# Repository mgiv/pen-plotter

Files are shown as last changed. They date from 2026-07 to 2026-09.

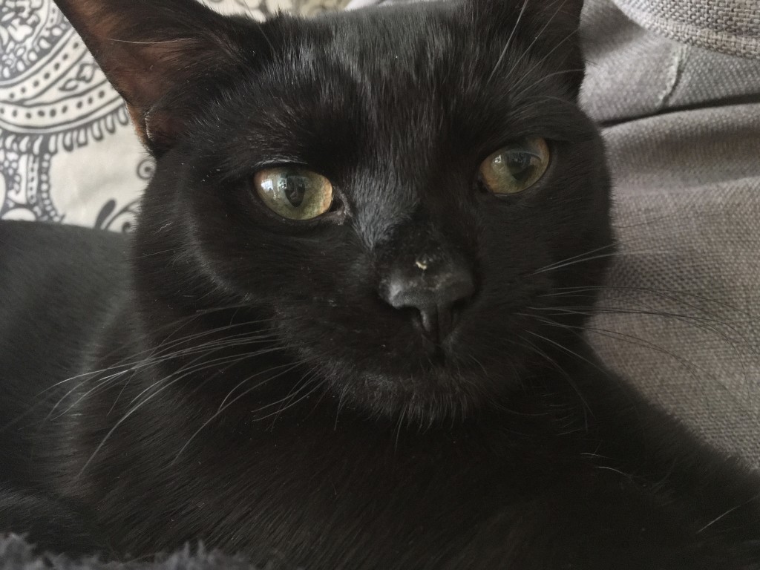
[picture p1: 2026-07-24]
code/TPGen/test-images/1.jpg

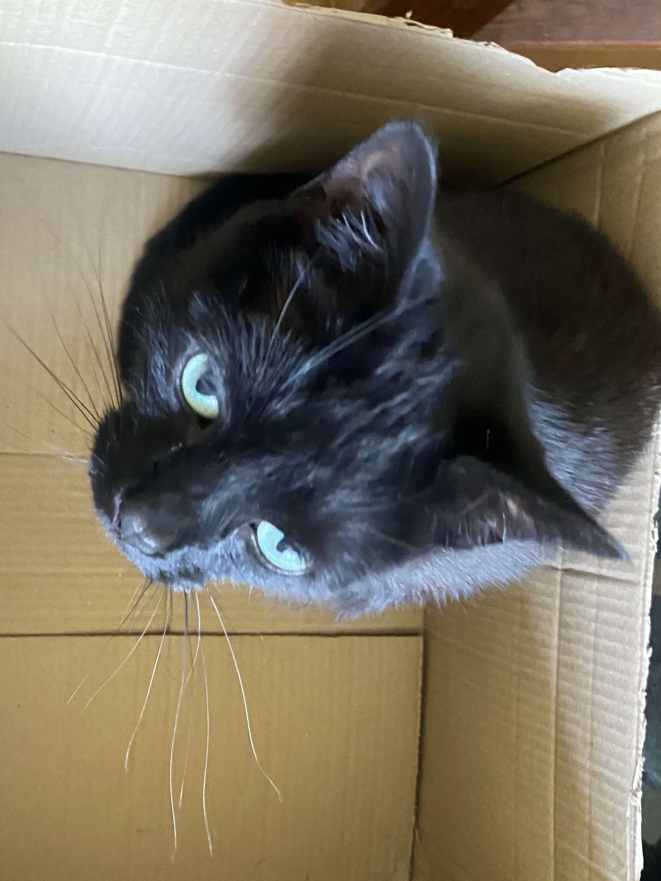
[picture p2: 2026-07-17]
code/TPGen/test-images/7.jpg

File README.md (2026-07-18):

# Pen plotter
## A simple pen plotter using an esp32, stepper motors, a servo and timing belts
### Demo videos
- [Demo 1 - Hilbert curves](https://www.youtube.com/watch?v=iywQXDerfF4)  
- [Demo 2 - Cat](https://www.youtube.com/shorts/F5tRbeLazfQ)  
- [Demo 3 - Triangles](https://www.youtube.com/shorts/Yr_N4DkdwpU)  
- [Demo 4 - Another Cat](https://www.youtube.com/shorts/lvt_kN0ZHD0)  

### Capabilities
#### It can convert images into lines, where the amount of lines shows the darkness of the pixels. Also, it can use canny edge detection to convert images into paths, and from there into drawings
cat  
{EF9DE653-6C88-40CC-B70B-28055ED8D5D0}

#### It can also draw hilbert curves and sierpinski triangles
{B3DB4044-183A-462D-B0FC-778355AC7D37}  
{AF7F2D5E-4E53-49CD-B731-9960951EA636}

#### Other features
- Auto Homing: Can return to (0, 0) automatically
- E-Stop Button: Stop suddenly when things go wrong
- Adjustable Pen Holder: Support for pens of all shapes and sizes
- Easy Assembly (Well... It's not that easy, but easier than the last version)
- Precise movement

### Design
The plotter uses a cartesian gantry system. Originally I was going to use a bed slinger system, like the Bambu Lab A1 Mini, however I decided to redesign it to corexy. After I realised how hard corexy would be to implement, I modified it to use the gantry.  
{F74FA99E-C383-4A17-BCB6-C585A155FD70}

There's 3 stepper motors, driven by 2 A4988 drivers. 2 of the motors are wired in series on the drivers, which makes sense since they're both on the y axis.

**Electronics**
- I used an ESP32, which is useful because it runs python, runs wifi, and is also far more capable than an arduino. I'm not using the wifi at the moment but might do later.
- The stepper drivers are A4988. I used generic breakout boards and soldered together a custom board with them that integrates the 2 of them with merged power, enable and gnd pins.
- The steppers are generic nema 17 motors, using 1/16 step
- The servo is a cheap SG90

### Print settings
- .28mm layer height, ~20-30% gyroid infill
- Auto supports
- Almost anything would work to be honest as long as it prints

### BOM
- 8mmx300mm steel linear rod (4x)
- M3 Nuts/Bolts
- NEMA 17 Stepper motors (3x)
- GT2 Timing belts (~3m)
- GT2 Spring belt tensioners (4-8x)
- GT2 Idlers (3x)
- GT2 Drive Pulleys (3x)
- Any random button/microswitch (3x)
- _Some_ M5 bolts (although 3d printed replacements would do)
- Wood screws/hot glue (anything to attach to baseboard)

### Build advice
If you want to print this yourself, I wouldn't recommend it. While it is in a working state, there are a lot of issues with the build that either make it a pain to build or just not work at all. If you do insist on building it yourself, find some random piece of wood or plastic to use as the baseboard. In a future version I'll improve the mounting holes and also make a semi-ridgid frame to help align it.

#### Instructions
1. Attach motors to parts using M3 screws.
2. Put the pen lift arm on the carriage
3. Assemble all the parts as shown without the timing belts. Take care not to bend the steel rods
4. Add the timing belts. Try to make them as tight as possible
5. If needed, add belt tensioning springs.
6. Wire the 2 Y axis motors in series
7. Either create or buy some dual stepper driver board (note that the 3 are treated as 2 motors because 2 of them are in series)
8. Press fit the servo into place, and (depending on print precision) add screws to hold in place if needed

### Credits
- Sierpinski triangle algorithm modified from https://runestone.academy/ns/books/published/pythonds/Recursion/pythondsSierpinskiTriangle.html
- Hilbert curve algorithm modified from https://www.compuphase.com/hilbert.htm
- Parts of edge detection algorithm modified from https://learnopencv.com/edge-detection-using-opencv/

### AI Usage
AI was used in doing research on components and design ideas, as well as for troubleshooting, and for advice about algorithms to use. It was also used for doing research on micropython and debugging code

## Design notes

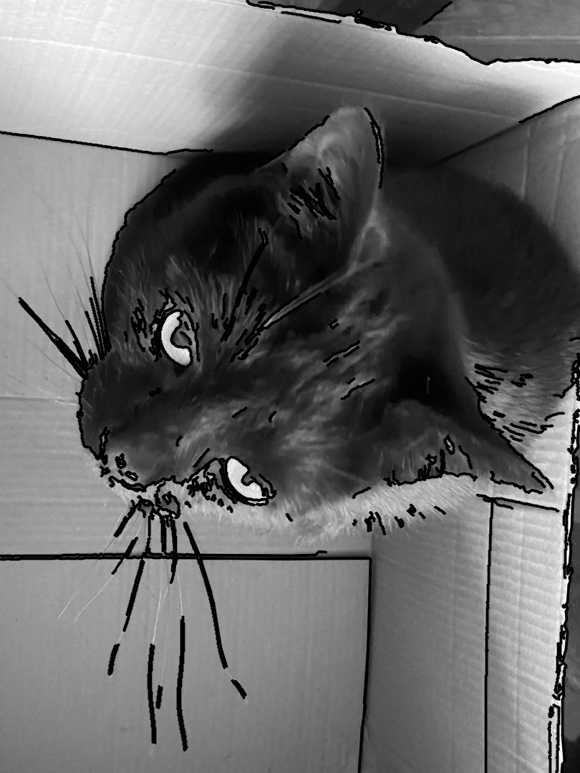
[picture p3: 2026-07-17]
code/TPGen/contours_none_image1.jpg

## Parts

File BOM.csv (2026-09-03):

Item Number | Part Name | Additional information | Quantity | Source | Unit cost (£) | Total cost (£)
1 | Stainess steel linear rods | 8mmx300mm | 4 | Purchased | £2.50 | £10
2 | NEMA 17 Stepper motor | 17HS4401 | 3 | Purchased | £7 | £21
3 | Pen | Any | 1 | Purchased | £1 | £1
4 | GT2 timing belt 6mm | ~2.5m | 1 | Purchased | £5 | £5
5 | GT2 timing belt motor pulleys |  | 3 | Purchased | £1 | £3
6 | GT2 timing belt idlers |  | 3 | Purchased | £1 | £3
7 | GT2 timing belt clamps | Aluminium clamps to hold belt | 3 | Purchased | £1 | £3
8 | GT2 belt tensioners |  | 0-6 | Purchased | £0.50 | £3
9 | SG90 Servo motor | With horn | 1 | Purchased | £2 | £2
10 | Microswitch | Tactile switch or any similar thing works fine | 2 | Purchased | £0.10 | £0.20
11 | M3 Screws / Nuts |  |  | Purchased |  | £5
12 | M5 Screws / Nuts | I used 3d printed versions, they're only for idlers | 3 | Purchased / 3D printed |  | £0-£5
13 | A4988 Stepper drivers |  | 2 | Purchased | £1 | £2
14 | Motor end 1 |  | 1 | 3D printed
15 | Motor end 2 | Mirrored version of motor end 1 | 1 | 3D printed
16 | Idler end 1 |  | 1 | 3D printed
17 | Idler end 2 | Mirrored version of idler end 2 | 1 | 3D printed
18 | XY motor connector |  | 1 | 3D printed
19 | XY idler connector |  | 1 | 3D printed
20 | Carriage |  | 1 | 3D printed
21 | Pen lift arm |  | 1 | 3D printed
22 | ESP32 board |  | 1 | Purchased | £3 | £3
23 | Prototype perfboard | Optional, can be used entirely on breadboard | 1 | Purchased | £1 | £1
24 | Breadboard |  | 1 | Purchased | £5 | £5
25 | Wires | Breadboard wires, thicker wires for power, stepper wires (should be included) | N/A | Purchased / Salvaged |  | £0-£5

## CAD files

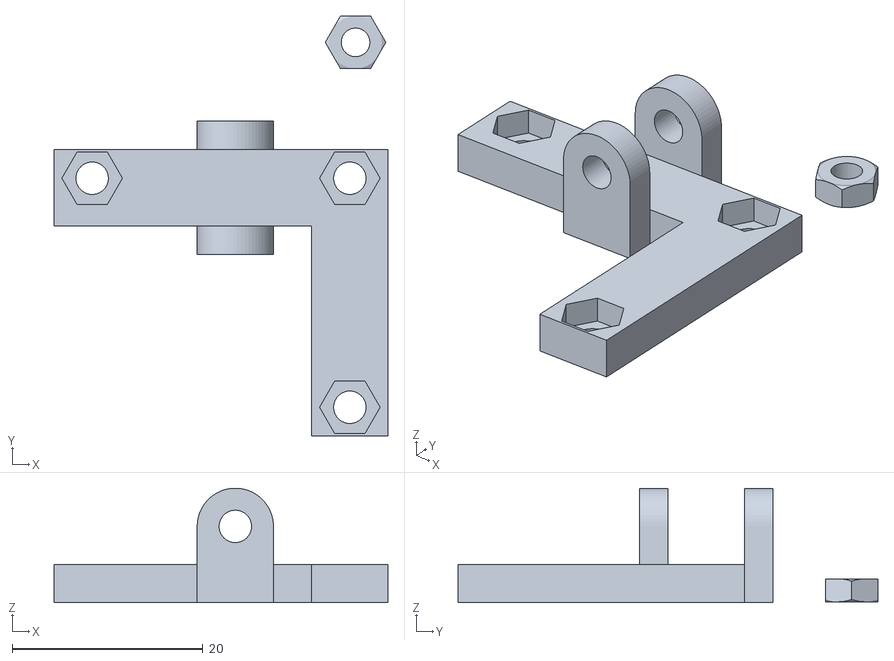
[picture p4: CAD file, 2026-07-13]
stl-corexy/PenLiftArmBase.stl
35.0 x 44.0 x 12.0

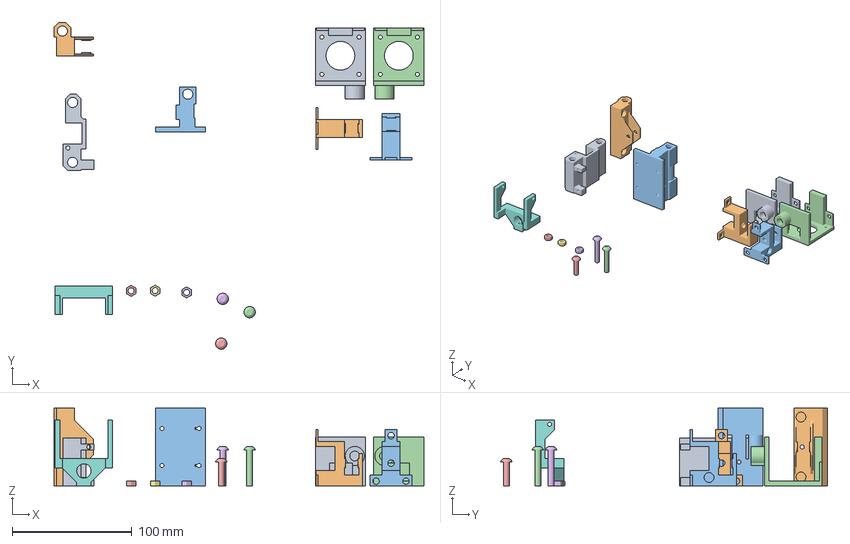
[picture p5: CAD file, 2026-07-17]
stl-gantry/Carriage.3mf
309.2 x 273.0 x 65.0 mm
Carriage.stl
IdlerEndLeft.stl
IdlerEndRight.stl
LeftMotorEnd.stl
m5-20mm.stl
m5-30mm.stl x 2
m5-nut.stl x 3
PenLiftArm.stl
RightMotorEnd.stl
XYConnectorIdler.stl
XYConnectorMotor.stl

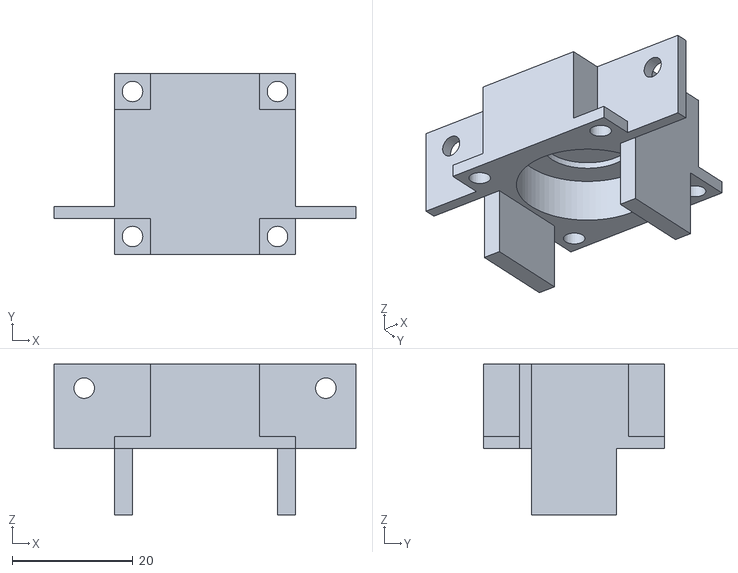
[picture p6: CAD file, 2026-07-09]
stl-x-proto/TopBearing.stl
50.0 x 30.0 x 25.0

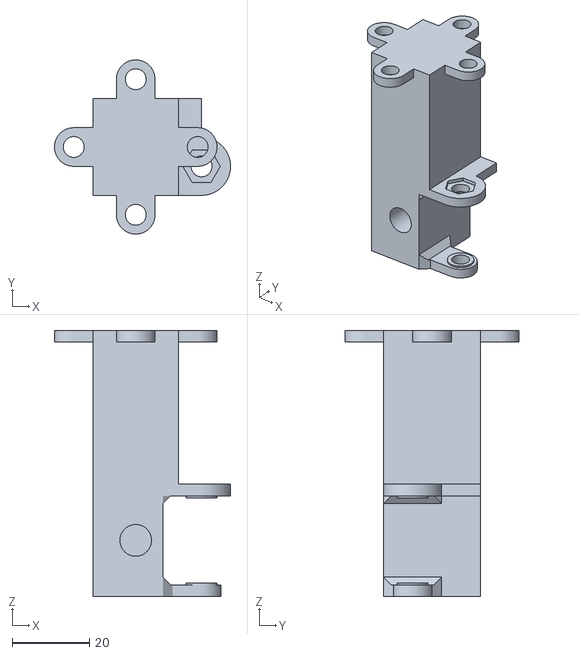
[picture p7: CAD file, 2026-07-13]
stl-corexy/EndIdler_Right.stl
45.5 x 45.0 x 68.7

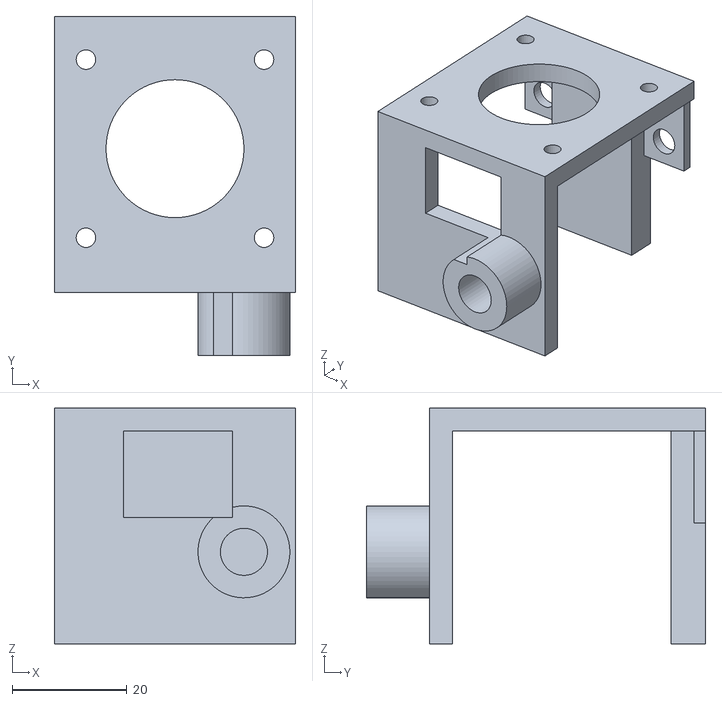
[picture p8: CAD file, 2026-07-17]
stl-gantry/LeftMotorEnd.stl
42.0 x 59.0 x 41.0

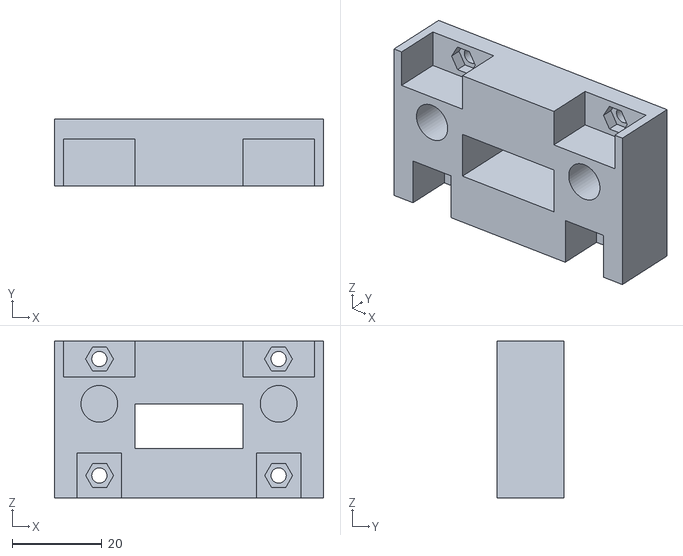
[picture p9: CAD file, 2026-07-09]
stl-x-proto/EndCap2.stl
60.0 x 15.0 x 35.0

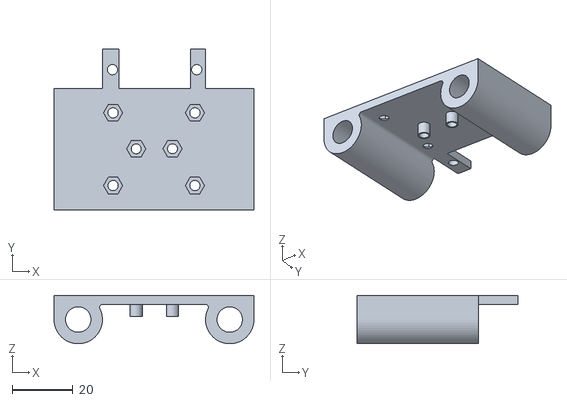
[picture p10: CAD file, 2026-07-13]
stl-corexy/Carriage.stl
66.0 x 53.0 x 16.0

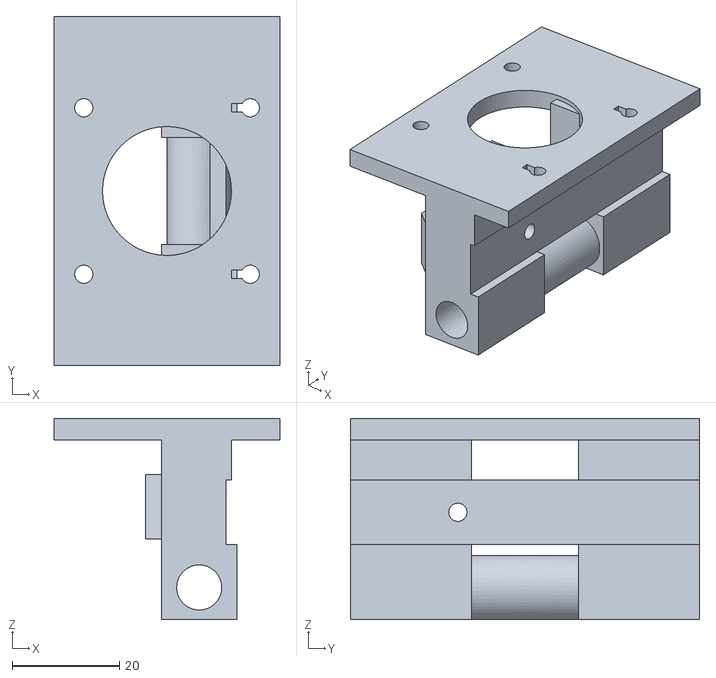
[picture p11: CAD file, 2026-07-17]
stl-gantry/XYConnectorMotor.stl
42.0 x 65.0 x 37.5

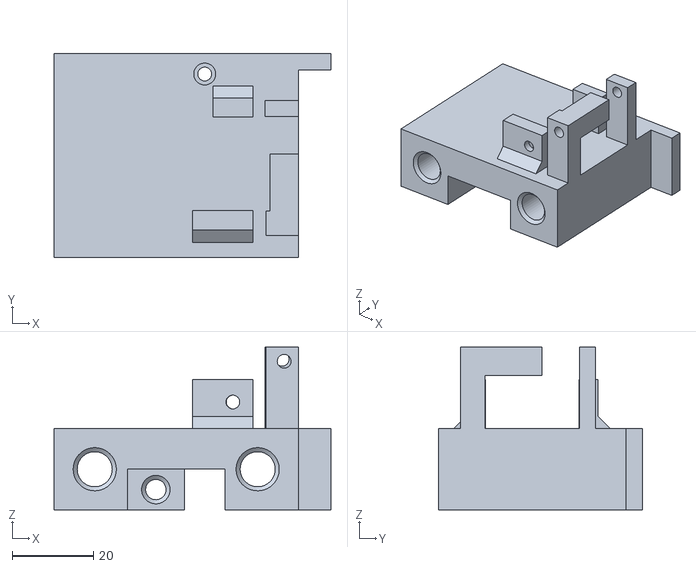
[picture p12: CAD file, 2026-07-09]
stl-x-proto/Carriage.stl
68.0 x 50.0 x 40.0

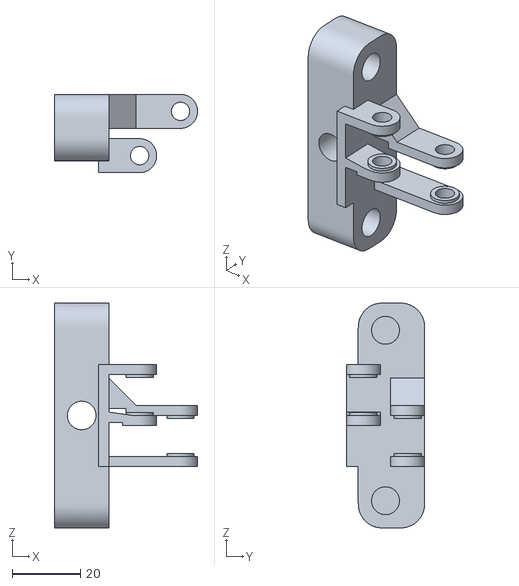
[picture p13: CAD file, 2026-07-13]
stl-corexy/XYAdapter_Right.stl
42.0 x 23.0 x 66.0

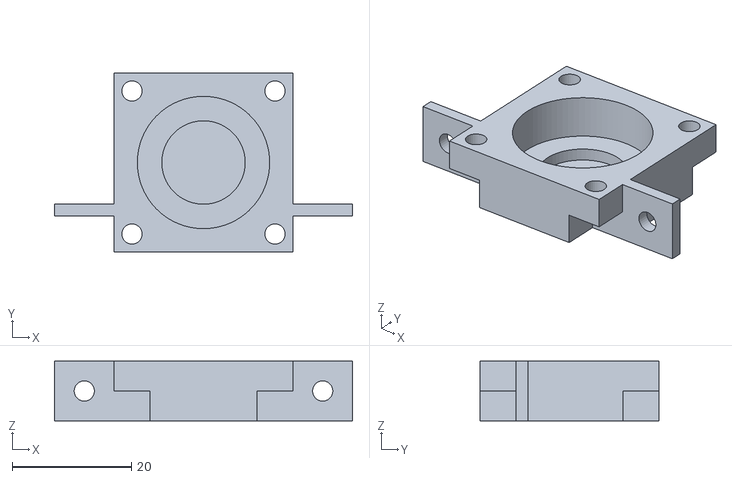
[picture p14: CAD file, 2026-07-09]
stl-x-proto/EndCap2Tensioner.stl
50.0 x 30.0 x 10.0

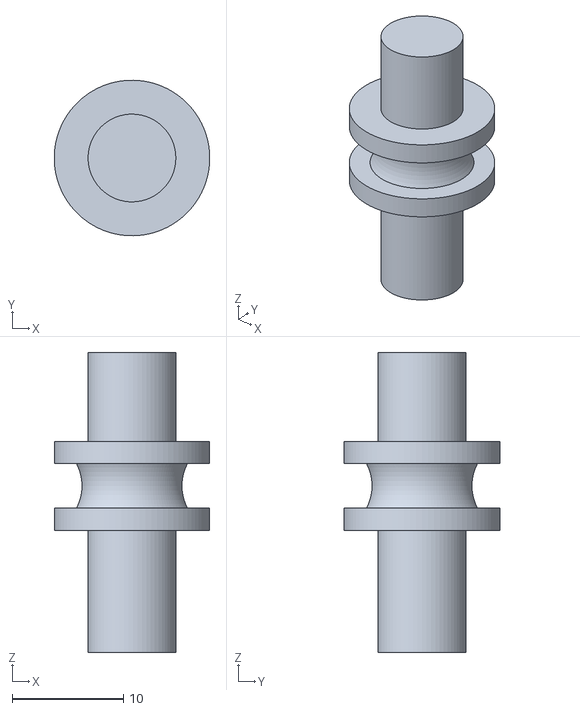
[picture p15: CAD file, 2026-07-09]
stl-x-proto/VerticalSpool.stl
14.0 x 14.0 x 27.0

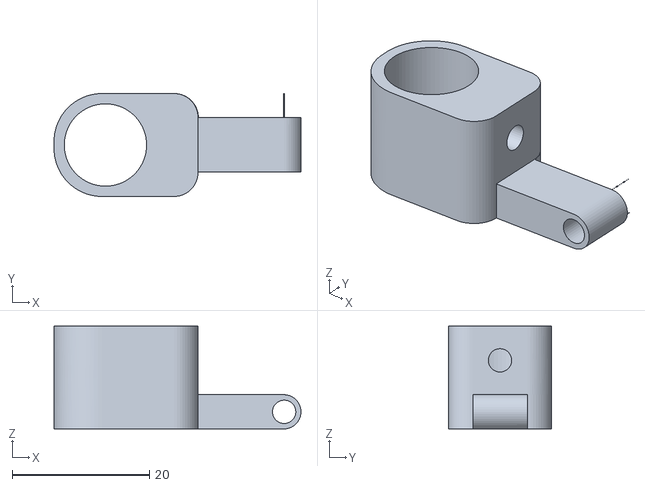
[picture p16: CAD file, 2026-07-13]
stl-corexy/PenHolder.stl
36.0 x 15.0 x 15.0

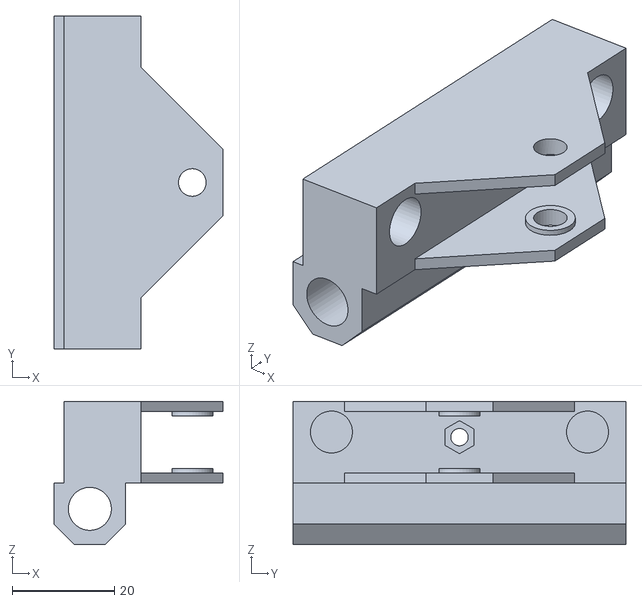
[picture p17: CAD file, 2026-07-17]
stl-gantry/XYConnectorIdler.stl
33.0 x 65.0 x 28.0

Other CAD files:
stl-corexy/EndIdler_Left.stl
stl-x-proto/Spool.stl
stl-corexy/Spacer.stl
stl-gantry/IdlerEndLeft.stl
f3d/Cartesian_v0.1.f3z
stl-corexy/EndCapLeft.stl
stl-corexy/EndCapRight.stl
stl-gantry/Carriage.stl
stl-gantry/IdlerEndRight.stl
stl-gantry/PenLiftArm.stl
stl-gantry/RightMotorEnd.stl
stl-gantry/m5-20mm.stl
stl-gantry/m5-30mm.stl
stl-gantry/m5-nut.stl
stl-x-proto/EndCap.stl
stl-x-proto/PenHolder.stl

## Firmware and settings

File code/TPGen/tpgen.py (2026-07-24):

import time

import numpy
from PIL import Image
import matplotlib.pyplot as plt
from matplotlib.colors import LinearSegmentedColormap
from matplotlib.collections import LineCollection
import hilbert
import triangle
import serial
import svg

import edge_detection
import line_converter

def handle_image(filename, reduce_quality=False):
    # Convert to greyscale
    img = Image.open(filename).convert("L")
    # Resize to make the image small enough
    if reduce_quality:
        img.thumbnail((100, 100))
    else:
        img.thumbnail((1920, 1080))

    pixels = numpy.array(img)
    return pixels

def draw(lines, sizex, sizey):
    # Strange wizardry to show the colours in order of drawing
    custom_cmap = LinearSegmentedColormap.from_list("progress", ["#ffff00", "#444400", "#ff0000", "#440000", "#ff00ff", "#440044", "#00ffff", "#004444"])
    colors = [custom_cmap(i / max(1, len(lines) - 1)) for i in range(len(lines))]

    # Matplotlib stuff copied from their examples page. Best to ignore for now
    fig, ax = plt.subplots(figsize=(10, 12), dpi=300)
    # set axes limits manually because Collections do not take part in autoscaling
    ax.set_xlim(0, sizex)
    ax.set_ylim(0,  sizey)
    ax.set_aspect("equal")  # to make the arcs look circular
    # create a LineCollection with the half-circles
    # its properties can be set per line by passing a sequence (here used for *colors*)
    # or they can be set for all lines by passing a scalar (here used for *linewidths*)
    line_collection = LineCollection(lines, linewidths=0.3, colors=colors)
    ax.add_collection(line_collection)

    plt.show()

# Simulation of what it might look like if it was drawn
def interpreter(commands):
    toolhead_pos = (0, 0)

    lines = []

    pen = "up"
    for command_num in range(len(commands)):
        command = commands[command_num].split(" ")
        if command[0] == "MOVE":
            x = 15000 - int(command[1])
            y = 15000 - int(command[2])
            if pen == "down":
                lines.append([toolhead_pos, (x, y)])

            # Move the toolhead anyway, even if we aren't drawing a line\\
            toolhead_pos = x, y

        elif command[0] == "PEN":
            if command[1] == "DOWN":
                pen = "down"
            elif command[1] == "UP":
                pen = "up"

            else:
                print("INVALID COMMAND: " + command)
        elif command[0] == "SPEED":
            pass


    return lines


def convert_image(filename, method, simulate=True):
    pixels = handle_image(filename, reduce_quality=True)

    y_size = len(pixels)
    x_size = len(pixels[0])

    x_size = len(pixels[0])
    y_size = len(pixels)

    sf = 15000 // x_size
    # Conver the image into a series of lines with the number depending on brightness
    if method == "lines":

        p_code = line_converter.line_convert(pixels, 10)
    # Do the same as above but first, use canny edge detection to filter out only the edges
    elif method == "edge_lines":
        pixels = handle_image(filename, reduce_quality=True)
        p_code = edge_detection.edge_lines(pixels)

    # Pure edge detection - takes the edges and turns that into lines that perfectly match the geometry
    # Much better looking images but harder to program
    elif method == "edge_pure":
        pixels = handle_image(filename, reduce_quality=False)
        p_code = edge_detection.pure_edge(pixels)

    else:
        print("Unknown method")
        return None
    return p_code


if __name__ == "__main__":
    # Image conversion - lines, edges then lines or pure edges
    # p_code = convert_image(f"test-images/4.jpg", "edge_pure", True)

    # Hilbert curve (level, width)
    #p_code = hilbert.hilbert(7, 15000)
    # Sierpinski triangle (level, width)
    #p_code = triangle.triangle(5, 15000)
    # Load SVG (filename, width)
    p_code = svg.draw_svg("test-images/sticker.svg", 15000, 5000, 1500)
    do_draw = True
    p_code.insert(0, "SPEED 5000")
    p_code.append("PEN UP")
    p_code.append("MOVE 0 0")
    if do_draw:
        print(len(p_code))
        lines = interpreter(p_code)
        draw(lines, 15000, 15000)
    p_code.append("MOVE 15000 16000")

    input("Ready to draw. Press any key to continue")

    start = 0
    with serial.Serial("COM9", 115200, timeout=None) as ser:
        pen = "up"

        print("Sending RST to device")
        ser.write("RST\n".encode("utf-8"))


        for instruction in range(start, len(p_code)):

            # Wait until an instruction is requested
            print("Waiting for instruction")
            while True:
                cmd = ser.readline().decode("utf-8")
                print(f"Received: {cmd}")
                if "NEXT" in cmd:
                    break
                elif "STOP" in cmd:
                    exit(1)

            inst = p_code[instruction]
            if inst == "PEN UP":
                pen = "up"
            elif inst == "PEN DOWN":
                pen = "down"
            print(f"Sending instruction: {inst} ({instruction})")
            ser.write((inst + "\n").encode("utf-8"))

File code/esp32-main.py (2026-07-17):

from stepper import Stepper
import time
import machine
from machine import Pin
from random import randint
import micropython
from servo import Servo
from math import sin, cos
import random
import sys
from collections import deque 
from time import ticks_us, ticks_diff

def deinit(pin=1):
    pen_up()
    
    x_axis.stop()
    y_axis.stop()

    en.value(1)
    time.sleep_ms(300)
    machine.soft_reset()


def irq_handler(pin=1):
    print("STOP")

    micropython.schedule(deinit, None)


# Allocate buffer in case of crash - doesn't seem to help but there's no harm
micropython.alloc_emergency_exception_buf(100)

# Kill switch - force reboots
e_stop = Pin(13, Pin.IN, Pin.PULL_UP)

e_stop.irq(trigger=machine.Pin.IRQ_RISING, handler=irq_handler)

y_axis = Stepper(
    18, 19, steps_per_rev=3200, speed_sps=5000, timer_id=1, invert_dir=True
)
x_axis = Stepper(
    16, 21, steps_per_rev=3200, speed_sps=5000, timer_id=0, invert_dir=True
)

# Down: 0
# Up: 30

srv = Servo(pin_id=25)

# Enable low = on, enable high = off
en = Pin(17, Pin.OUT)

end_swy = Pin(15, Pin.IN, Pin.PULL_UP)
end_swx = Pin(4, Pin.IN, Pin.PULL_UP)

def pen_up():
    srv.write(40)
    time.sleep_ms(100)

def pen_down():
    srv.write(0)
    time.sleep_ms(100)

x_pos = 0
y_pos = 0
speed = 5000

def home():
    en.value(0)
    pen_up()
    # X axis
    x_axis.speed(500) #use low speed for the calibration
    x_axis.free_run(-1)
    while end_swx.value(): #wait till the switch is triggered
        time.sleep_ms(1)
    x_axis.stop() #stop as soon as the switch is triggered
    
    y_axis.speed(500) #use low speed for the calibration
    y_axis.free_run(-1)
    while end_swy.value(): #wait till the switch is triggered
        time.sleep_ms(1)
    y_axis.stop() #stop as soon as the switch is triggered
    
    move (100, 100)
    x_pos = 100
    y_pos = 100



@micropython.native
def move(t_x, t_y):
    # Increase speed in hundredths of the original speed
    speed_add_amount = speed // 25
    cur_speed = speed_add_amount
    
    global x_pos
    global y_pos
    
    # Steps needed 
    sn_x = abs(t_x - x_pos)
    sn_y = abs(t_y - y_pos)
    # More steps needed in x (or the same, but that doesn't change anything
    if sn_x >= sn_y:
        sn = sn_x
    else:
        sn = sn_y
        
    # Short line - set to full speed
    if sn < 100:
        cur_speed = speed
    sn = 1000
        
    # Steps taken
    st = 0
    
    if t_x > 15000 or t_y > 16000 or t_x < 0 or t_y < 0:
        return
    # XY0 = Old
    # XY1 = New
    # Draw point from xy0 to xy1
    
    # Distance from x0 to x1
    dx = abs(x_pos - t_x)
    # Sign value
    if x_pos < t_x:
        sx = 1
    else:
        sx = -1
        
    # Distance from y0 to y1    
    dy = -abs(y_pos - t_y)
    # Sign value
    if y_pos < t_y:
        sy = 1
    else:
        sy = -1
    error = dx + dy
    
    next_step_time = ticks_us()
    
    while True:
        # At the target
        if x_pos == t_x and y_pos == t_y:
            break
        e2 = 2 * error
        step_x = 0
        step_y = 0
        
        if e2 >= dy:
            if x_pos == t_x:
                break
            error += dy
            x_pos += sx
            step_x += sx
        
        if e2 <= dx:
            if y_pos == t_y:
                break
            error += dx
            y_pos += sy
            step_y += sy
        
        # Wait 200us - we have to do this as the instructions may take a few us, which would make things slower
        while ticks_diff(next_step_time, ticks_us()) > 0:
            pass
        
        # Still at the start
        if cur_speed < speed:
            cur_speed += speed_add_amount
        # We're approaching the end - 25 steps to go
        elif sn - st <= 25:
            cur_speed -= speed_add_amount
            
            
        next_step_time += (1_000_000 // cur_speed)
        
        st += 1
        
        
        if step_x != 0:
            x_axis.step(step_x)
        if step_y != 0:
            y_axis.step(step_y)
        

def main():
    global speed

    cur_x = 0
    cur_y = 0
    pen_up()
    en.value(0)
    home()
    print("NEXT")
    while True:
        command = sys.stdin.readline()

        if not command:  # EOF
            break
    
        print("NEXT")
      
       
        
        # Remove trailing newcommand
        command = command.strip().upper()
        if not command:
            print("NEXT")
            continue
        command = command.split(" ")
        
        if command[0] == "MOVE":
            new_x = int(command[1])
            new_y = int(command[2])
            move(new_x, new_y)
            
        elif command[0] == "PEN":
            if command[1] == "DOWN":
                pen_down()
            elif command[1] == "UP":
                pen_up()
            else:
                print("INVALID COMMAND: " + line)

        elif command[0] == "SPEED":
            # Min speed 100
            if speed >= 100:
                speed = int(command[1])
        elif command[0] == "HOME":
            x_pos = 0
            y_pos = 0
            home()
        elif command[0] == "RST":
            deinit()
    
    pen_up()
    home()

try:
    main()
except KeyboardInterrupt:
    deinit()

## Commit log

2026-07-08 Repo Init
    [Carriage.stl, EndCap.stl, EndCap2.stl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]
2026-07-09 Prototype 2 (first usable version)
    [Carriage.stl, EndCap.stl, EndCap2.stl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]
2026-07-13 update git repo for new version
    [Carriage.stl, Cartesian_v0.1.f3z, EndCap.stl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]
2026-07-17 Ready to ship
    [Carriage.3mf, Carriage.stl, EndCap.stl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]
2026-07-18 Enhance README with print settings and build instructions
    Added print settings, BOM, build advice, and assembly instructions to README.
2026-09-03 Add BOM
    [bill_of_materials.csv]
